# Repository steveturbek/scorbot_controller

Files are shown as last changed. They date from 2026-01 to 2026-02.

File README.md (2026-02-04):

# Scorbot Robot Controller

## Description

Arduino-based motor controller and software for rescued Scorbot ER III robot arm. MIT License.

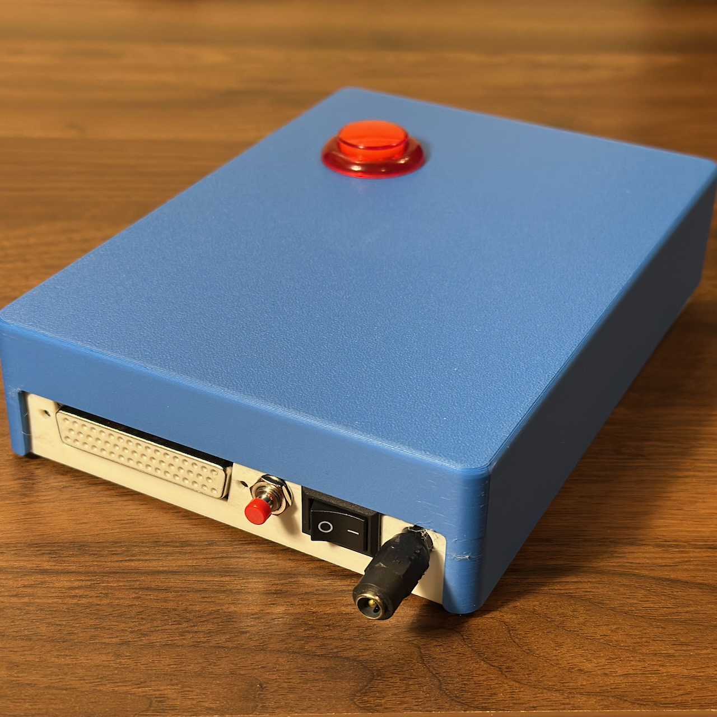
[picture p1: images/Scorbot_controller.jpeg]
Scorbot controller hardware

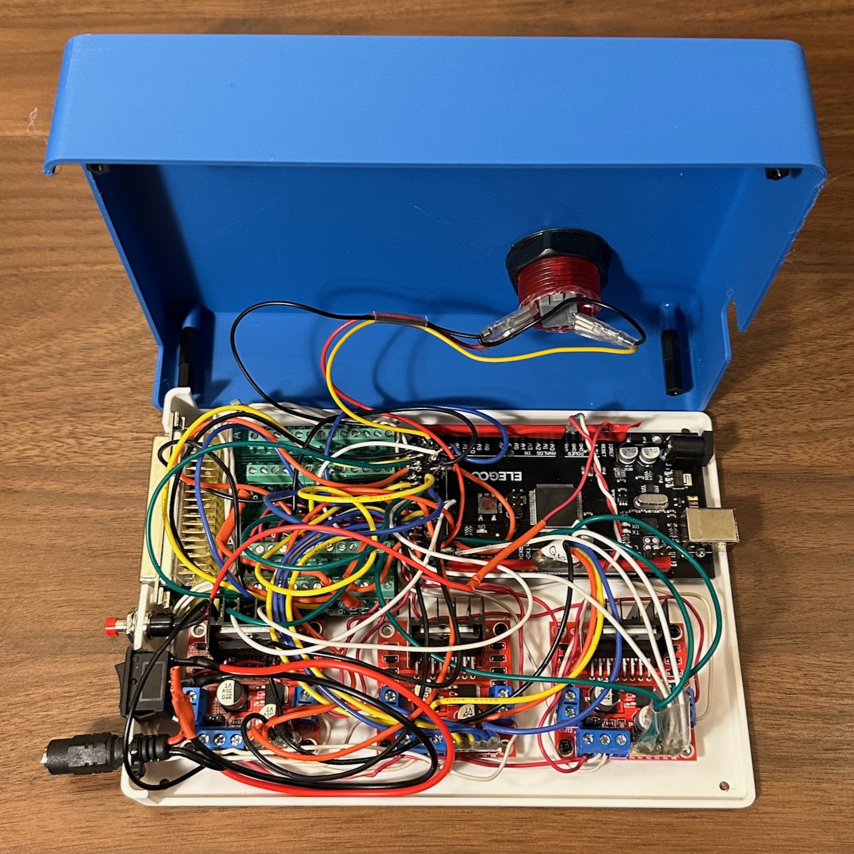
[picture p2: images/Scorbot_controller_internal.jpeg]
Scorbot controller hardware Internal


<video autoplay muted loop playsinline id="myVideo">
<source src="images/scorbot.mp4" type="video/mp4" />
</video>

[Video of Scorbot start up and simple motion demo](https://turbek.com/scorbot_controller/images/scorbot.mp4)

## Current Status

**Project Status: Complete (Hibernating)**

The controller is a demonstration of reviving a Scorbot ER III:

- All 6 axes move with PWM speed control
- All axes home correctly (gripper uses stall detection, others use microswitches)
- Position-based movement via encoder feedback
- Differential wrist control (pitch and roll motors work together)
- Goal-based queue system for sequencing movements
- Emergency stop functionality
- Demo sequence: homes all axes → picks up item → flips it → relocates

## Software Quick Start

1. **Upload firmware**: Load `scorbot_controller.ino` to Arduino Mega using Arduino IDE
2. **Connect Serial Monitor**: 115,200 baud to see debug output
3. **Power on**: Robot will home all axes sequentially, then run the demo sequence
4. **Modify behavior**: Edit the `setup()` function in `scorbot_controller.ino` to change the movement sequence

### Example: Adding a movement to the queue

```cpp
// Create a new goal group (movements in a group run in parallel)
queueCreateGoalGroup("move base and shoulder");
queueAddGoal(MOTOR_BASE, GOAL_MOVE_TO, 1050);      // Move base to position 1050
queueAddGoal(MOTOR_SHOULDER, GOAL_MOVE_TO, -500);  // Move shoulder to -500

// Wait 1 second before next group
queueCreateGoalGroupWait(1000);

// Gripper grab (move until stall detected)
queueCreateGoalGroup("grab item");
queueAddGoal(MOTOR_GRIPPER, GOAL_MOVE_TILL_STALL, 50);
```

## Key Code Entry Points

| File | Purpose |
| --- | --- |
| `scorbot_controller.ino` | Main firmware - modify `setup()` to change demo sequence |
| `scorbot.h` | Pin definitions, motor structs, speed thresholds |
| `helpers/pin_test/` | Diagnostic utility for verifying wiring |

### Key Functions

- `queueCreateGoalGroup(name)` - Start a new parallel movement group
- `queueAddGoal(motor, goalType, target)` - Add a motor goal to current group
- `queueCreateGoalGroupWait(ms)` - Add a pause between groups
- `queueAddGoalsFindHomeAll()` - Home all axes sequentially
- `queueStart()` - Begin executing the queue

### Goal Types

- `GOAL_FIND_HOME` - Search for home switch with edge detection
- `GOAL_MOVE_TO` - Move to encoder position
- `GOAL_MOVE_TILL_STALL` - Move until motor stalls (useful for gripper)

## Known Quirks & Lessons Learned

- **High PWM required**: Motors need high PWM values to overcome static friction. Elbow requires PWM 255; most others need 200+. See `motor_min_CW/CCW` in `scorbot.h`.
- **Stall detection timing**: Shoulder and Wrist Pitch are sensitive and need longer stall detection (400ms vs 100ms for others)
- **Gripper has no microswitch**: Uses stall detection when closed for homing
- **Differential wrist**: Wrist Pitch and Roll motors are mechanically coupled. Pure pitch = both same direction; pure roll = opposite directions. Handled automatically in firmware.
- **Home base last**: Base swings wildly during homing - the code homes it last for safety
- **Elbow issues**: Had mechanical problems during development; pin 27 connection was loose

## Potential Future Steps

The project is complete as a demostration of reviving the Scorbot, but future exploration could include:

- [] add direct joystick control
- [] add Microbit remote control for student project
- [] define and make a demo program, like moving a chess piece from one position to another
- [] define a way to write, store and load "programs" as external files
- [] measure end stops/stalls for each motor; update scorbot.h definitions
- [] Write "clean up" function to position motors near switches so the start up homing process goes faster
- [] add move to end/stall and stop function (good for picking up item with gripper)

## Project Log

- January 2026
  - Rough layout of parts on a board - the motors move!
  - modeled and printed controller case. Much easier thinking after just picking a layout. next time would just print base and areas under the ports.
  - Wired up mega, DB-50 connector and 3 L298N's. My soldering skills are very limited. I would use screw terminal shield for the Arduino Mega next time.
  - motors are working, basically. appear a bit slow, but power supply seems to be working. Desktop power supply reads roughly .5amps when motors are running.
  - the motors seems to need a high PWM value to move at all. I tested voltage across 12v power supply and PWM and appear in range.
  - `scorbot.h` is where I'm storing definitions and shared functions
  - `/helpers/` has working test files
  - `helpers/pin_test/pin_test.ino` was looking for shorts, etc in the arduino mega pins, due to my clumsy work. surprisingly I got it right on the first try
  - `helpers/motor_only_test/motor_only_test.ino` just moves the motors back and forth
  - `helpers/base_motor_test/base_motor_test.ino` is testing for homing and encoders for just the base motor
  - [Scorbot ER-4U](https://www.theoldrobots.com/book45/ER4u_User_Manual.pdf) seems to be essentially the same machine
  - note that Shoulder, Elbow, Wrist Pitch are built in such a way that wrist pitch remains consistent relative as shoulder and elbow move. Moving the shoulder does NOT simply swing the gripper tip relative to the shoulder. Moving the shoulder rotates the elbow to keep the wrist pitch steady. This is cool / confusing. probably needs kinematics
  - Arduino IDE is pretty slow. VS Code extension for arduino has been deprecated. PlatformIO looks too complicated for this project. Arduino Community Edition might work, but CLI, etc are too complicated at this point
  - installed CLANG to VSCode to get linting/formatting
  - MOTOR_ELBOW was a big pain, would not go CCW. turned out the CCW pin (arduinio pin 27) was loose
  - added Queue system to make sequence of actions

  - [x] add move to position
  - [x] add queue of goals, with parallel and sequential steps
  - [x] add all stop with interrupt
  - [x] make 'home' the CW clockwise side of the microswitch. there are ~200 encoder steps where the switch is depressed as the arm moves across the button.
  - [x] gripper home is stall when closed
  - [x] wrist pitch and roll movements depend on motors 4-5 working together differential drive
  - [x] shoulder find home
  - [x] write arduino code to get arm to move to home position
  - [x] make replacement microswitch cams
  - [x] 3D model top of case

- December 2025
  - modeled `scorbot joint cover with microswitch cam.stl`, printed and replaced cams. 1 original cam remains
  - ordered L298Ns, Arduino Mega, power supply

- August 2025
  - Got Scorbot ER III discarded by friends at NYC First. No controller or documentation
  - serial number 2090047 model "robot"
  - identified it as scorbot ER iii, found documentation and github projects.
  - Motors can be moved with basic 12v .5A power.
  - Gripper does not move, carefully opening it, seems like encoder case is bent, propellor hitting encoder and LEDs
  - Wrist roll microswitch is hanging off, which may be related.
  - I'm going to run motors on 12v power
  - all 5 microswitch work from switch leads and the pins
  - microswitch cam discs that trigger switches at home point are broken for shoulder, elbow, wrist. for shoulder, using broken pieces, looks like trigger radius is 30mm, clearance is 26-28mm. cup depth is 10mm, center hole dia is 6mm
  - Repaired the Gripper motor and the encoder, which was banged in. microswitch re-attached
  - gripper motor plate uses unusual 3.5mm hex for screws
  - using multimeter on Gripper and base, it seems motor encoders work!
  - Motors do NOT have auto stop switches at ends of rotation. assume they do it in software
  - cams are missing, but based on base, the 'home' position, where microswitch is, should be the center of movement.
  - confirmed Gripper encoder works, hand spinning disc. 47 ohm resistor works to LED. LED is infrared, not visible. photoresistor needs 10k pull up to 5v each to pin 0 and 1, where signal is read. (Arduino has this built in)
  - assuming other encoders work, proceeding with buying parts
  - arduino mega has 5v outputs
  - L298N H bridge enable pins can be PWM'd for speed control

### Project Goals

This is a messing around, learning project inspired by a free robot arm. The Scorbot ER III is a circa 1995 robot. So simple, maybe even I can work with it!

The goals of the project are to

1. Learn
1. Restore the basic functionality of movement and encoders
1. Design and build an arduino based controller that accepts a joystick-type controller and data input to operate.
1. Enable design students to design and build a microbit based joystick controller
1. Design and build a case

### When might I quit this project?

- If motors, or encoders stop working
- If costs go above $200
- If effort goes beyond a few weeks

## Project Parts List

- Scorbot ER iii robot arm, without controller or Teaching pendant (~$400-1000)
- [Arduino-type Mega board](https://a.co/d/h9p4QL3)
- [D-50 style connector board](https://a.co/d/717fIG9)
- [L298N dual h bridge motor controller](https://a.co/d/8DAa5Af)
- [12v 10 amp power supply](https://a.co/d/0ydMZDN)

## Scorbot Description

[Scorbot ER III Manual](/references/ER3-Manual.pdf)

### Summary

| Specification | Value |
| **Mechanical Structure** | Vertically articulated |
| **Axes** | 5 axes plus gripper |
| **Control** | 8 axes simultaneously |
| **Working Envelope** | |
| Axis 1: Base Rotation | 310° |
| Axis 2: Shoulder Rotation | +130° / –35° |
| Axis 3: Elbow Rotation | ±130° |
| Axis 4: Wrist Pitch | ±130° |
| Axis 5: Wrist Roll | Unlimited |
| **Maximum Working Radius** | 610 mm (24.4") |
| **Gripper Opening** | 75 mm (3") without rubber pads<br>65 mm (2.56") with rubber pads |
| **Maximum Work Load** | 1 kg (2.2 lb.) |
| **Transmission** | Gears, timing belts and lead screw |
| **Actuators** | 6 DC servo motors with closed-loop control |
| **Feedback** | Optical encoders on all axes |
| **Hard Home** | Fixed reference position on all axes |
| **Repeatability** | ±0.5 mm (±0.02") |
| **Maximum Speed** | 330 mm/sec. (13"/sec.) |
| **Weight** | |
| Robot Arm | 11 kg (24 lb.) |
| Controller | 5 kg (11 lb.) |

### Original power supply

- - 15V, 4A, unregulated, supplies power to the robot motors.
- –15V, 4A, unregulated, supplies power to the robot motors.
- - 5V, 1.5A, regulated, supplies power to the microprocessor, the memory and the logic in the control circuit.
- - 12V, 0.4A, regulated, supplies power to the I/O circuitry outputs, and to the RS232 communications.
- –12V, 0.4A, regulated, supplies power to the RS232 communications.

### Motors

- Motors 1,2,3 Pittman GM9413G608 127.7:1 ratio
- Motors 4,5 Pittman GM9413F759 65.5:1 ratio
- Motor 6 Gripper Pittman GM8712F297 19.5:1 ratio

### Scorbot Cable connector

The Scorbot cable connector is an [DB 50](https://en.wikipedia.org/wiki/D-subminiature) cable. Connectors and breakout boards that fit are available at Amazon or Ali Express. [DB 50 connector Specification](https://www.farnell.com/datasheets/1656989.pdf) [DB50 diagram](https://upload.wikimedia.org/wikipedia/commons/a/af/DD50_Diagram.svg)

Here is the pin numbers (looking at the male scorbot cable connector pins)

<pre>
────────────────────────────────────────────────────────────────────────────────────────────
╲   (1)  (2)  (3)  (4)  (5)  (6)  (7)  (8)  (9)  (10) (11) (12) (13) (14) (15) (16) (17)   ╱
 ╲    (18) (19) (20) (21) (22) (23) (24) (25) (26) (27) (28) (29) (30) (31) (32) (33)     ╱
  ╲ (34) (35) (36) (37) (38) (39) (40) (41) (42) (43) (44) (45) (46) (47) (48) (49) (50) ╱
    ─────────────────────────────────────────────────────────────────────────────────────
</pre>

## SCORBOT ER III WIRING GUIDE

### TABLE 1: DB-50 CONNECTOR TO ARDUINO MEGA

| DB-50 Pin | Motor | Joint | Signal | Arduino Pin | L298N Board | L298N Input | L298N Output | Notes |
| --- | ----- | --- | --- | --- | --- | --- | --- | --- |
| 1 | 2 | Shoulder | Encoder P0 | 36 | | | | |
| 2 | 1 | Base | Encoder P0 | 34 | | | | |
| 3 | 5 | Wrist Roll  | Encoder P1 | 43 | | | | |
| 4 | 3 | Elbow | Encoder P1 | 39 | | | | |
| 5 | 1 | Base | Encoder P1 | 35 | | | | |
| 6 | 5 | Wrist Roll  | Microswitch | 50 | | | | |
| 7 | 2 | Shoulder | Microswitch | 47 | | | | |
| 8 | 4 | Wrist Pitch | Microswitch | 49 | | | | |
| 9 | 5 | Wrist Roll  | Encoder LED | 5V via 47Ω  | | | | |
| 10 | 3 | Elbow | Encoder LED | 5V via 47Ω  | | | | |
| 11 | 1 | Base | Encoder LED | 5V via 47Ω  | | | | |
| 12 | 6 | Gripper | Motor + | 32 | 3 | 3 | 3 | |
| 13 | 5 | Wrist Roll  | Motor + | 30 | 3 | 1 | 1 | |
| 14 | 4 | Wrist Pitch | Motor + | 28 | 2 | 3 | 3 | |
| 15 | 3 | Elbow | Motor + | 26 | 2 | 1 | 1 | |
| 16 | 2 | Shoulder | Motor + | 24 | 1 | 3 | 3 | |
| 17 | 1 | Base | Motor + | 22 | 1 | 1 | 1 | |
| 18 | 5 | Wrist Roll  | Encoder P0 | 42 | | | | |
| 19 | 6 | Gripper | Encoder P1 | 44 | | | | |
| 20 | 4 | Wrist Pitch | Encoder P1 | 41 | | | | |
| 21 | 2 | Shoulder | Encoder P1 | 37 | | | | |
| 22 | 6 | Gripper | Microswitch | - | | | | manual says not connected |
| 23 | 1 | Base | Microswitch | 46 | | | | |
| 24 | 3 | Elbow | Microswitch | 48 | | | | |
| 25 | 6 | Gripper | Encoder LED | 5V via 47Ω  | | | | |
| 26 | 4 | Wrist Pitch | Encoder LED | 5V via 47Ω  | | | | |
| 27 | 2 | Shoulder | Encoder LED | 5V via 47Ω  | | | | |
| 28 | 6 | Gripper | Encoder GND | GND | | | | |
| 29 | 5 | Wrist Roll  | Switch & Encoder GND | GND | | | | |
| 30 | 4 | Wrist Pitch | Switch & Encoder GND | GND | | | | |
| 31 | 3 | Elbow | Switch & Encoder GND | GND | | | | |
| 32 | 2 | Shoulder | Switch & Encoder GND | GND | | | | |
| 33 | 1 | Base | Switch & Encoder GND | GND | | | | |
| 34 | 6 | Gripper | Encoder P0 | 45 | | | | |
| 35 | 4 | Wrist Pitch | Encoder P0 | 40 | | | | |
| 36 | 3 | Elbow | Encoder P0 | 38 | | | | |
| 37 | - | - | - | - | | | | |
| 38 | - | - | - | - | | | | |
| 39 | - | - | - | - | | | | |
| 40 | - | - | - | - | | | | |
| 41 | - | - | - | - | | | | |
| 42 | - | - | - | - | | | | |
| 43 | - | - | - | - | | | | |
| 44 | - | - | - | - | | | | |
| 45 | 6 | Gripper | Motor - | 33 | 3 | 4 | 4 | |
| 46 | 5 | Wrist Roll  | Motor - | 31 | 3 | 2 | 2 | |
| 47 | 4 | Wrist Pitch | Motor - | 29 | 2 | 4 | 4 | |
| 48 | 3 | Elbow | Motor - | 27 | 2 | 2 | 2 | |
| 49 | 2 | Shoulder | Motor - | 25 | 1 | 4 | 4 | |
| 50 | 1 | Base | Motor - | 23 | 1 | 2 | 2 | |
| - | 1 | Base | PWM (motor speed) | 7 | 1 | | ENA | |
| - | 2 | Shoulder | PWM (motor speed) | 6 | 1 | | ENB | |
| - | 3 | Elbow | PWM (motor speed) | 5 | 2 | | ENA | |
| - | 4 | Wrist Pitch | PWM (motor speed) | 4 | 2 | | ENB | |
| - | 5 | Wrist Roll  | PWM (motor speed) | 3 | 3 | | ENA | |
| - | 6 | Gripper | PWM (motor speed) | 2 | 3 | | ENB | |
| - | - | - | - | 52 | | | | Emergency Stop Button |

### TABLE 2: POWER CONNECTIONS

| Component | Connection | Source | Notes |
| --- | --- | --- | --- |
| Arduino Mega | 12V Vin | Common 12v plug or Barrel Jack | Powers logic |
| Arduino Mega | GND | Common Ground | Shared with all components |
| L298N Board 1-3 | 12V | 12V 10A Power Supply | Motor power |
| L298N Board 1-3 | GND | Common Ground | Shared ground |
| Encoder LEDs (6x) | 5V | Arduino 5V via 47Ω resistor | One resistor per encoder |
| Encoder LEDs GND  | GND | DB-50 pins 28-33 | Common ground |

### SERIAL COMMUNICATION

| Function | Arduino Pin | Purpose |
| --- | --- | --- |
| TX | 18 | Serial1 - transmit to joystick controller  |
| RX | 19 | Serial1 - receive from joystick controller |

### WIRING TIPS

1. **Label everything** - use labels/tape on wires at both ends
2. **Color coding:**
   - Red: 12V power
   - Black: GND
   - Yellow/Green: encoders
   - Blue: microswitches
   - Other colors: motor control signals
3. **Use a breakout board** for the DB-50 connector
4. **Bundle by function** - keep motor, encoder, and switch wires separated
5. **Consider a prototype shield** or custom PCB for clean organization

## Spec sheets and Manuals

- [Scorbot ER III Manual](https://www.theoldrobots.com/book45/ER3-Manual.pdf)
- [Arduino Mega sheet](https://content.arduino.cc/assets/Pinout-Mega2560rev3_latest.pdf)
- [Arduino Mega details](https://docs.arduino.cc/hardware/mega-2560/)
- [L298N dual H bridge motor controller](https://www.handsontec.com/dataspecs/L298N%20Motor%20Driver.pdf)

## CAD

- [SCORBOT ER4u Robotic Arm](https://grabcad.com/library/scorbot-er4u-robotic-arm-1)
- [L298N dual H bridge motor controller](https://grabcad.com/library/motor-driver-l298n-2)
- [DB50 Connector](https://grabcad.com/library/panel-connector)
- [DB50 dimensions](https://my.misumi-ec.com/linked/item/10500001630/img/SEA_oth_04large.gif)
- [Arduino Mega](https://grabcad.com/library/arduino-mega-17)

## Diagrams

Arduino Mega

DB50 Breakout board

DC motor

L298N motor controller

## Scorbot GitHub Projects

| Project Name | Associated Web Pages | Brief Description |
| --- | --- | --- |
| [**Scorbot**](https://github.com/amiravni/Scorbot) | • [GitHub](https://github.com/amiravni/Scorbot/blob/master/scorbotOldTestCode/ScorbotCmd/ScorbotCmd.ino) <br>[My Name is Scorbot](http://www.whatimade.today/my-name-is-scorbot/)<br> [Scorbot learns to draw"](http://whatimade.today/geekcon-xii-scorbot-learns-to-draw/) | Arduino MEGA-based controller for Scorbot ER-V with 6-encoder system, custom PCB shield, and Python drawing capabilities. Complete reverse engineering from junkyard condition. |
| [**robotic-arm**](https://github.com/ethanleep/robotic-arm) | • [Scorbot ER-III Manual](https://usermanual.wiki/Document/Scorbot20ERIII20manual.259237025/help) | Custom controller replacement for Scorbot-ER III with serial and hard-coded control modes. Arduino-based system with comprehensive reference documentation. |
| [**Scorbot**](https://github.com/luisp23/Scorbot) | • [Author's Portfolio](https://www.luispimen.com/)<br>• [CS 287: Advanced Robotics Course](https://people.eecs.berkeley.edu/~pabbeel/cs287-fa19/) | Arduino-based joystick controller for Scorbot robotic arm as cost-effective alternative to expensive original controller. Georgia Tech ECE project. |
| [**Scorbot-ER-V-Simulator-Controller**](https://github.com/aamitn/Scorbot-ER-V-Simulator-Controller) | • [Hackster.io Project](https://www.hackster.io/amitnandileo/scorbot-er-v-controller-simulator-design-1a2d6f)<br>• [Arduino Project Hub](https://create.arduino.cc/projecthub/amitnandileo/scorbot-er-v-controller-simulator-design-1a2d6f)<br>• [Author's Website](https://aamitn.github.io/)<br>• [ResearchGate Profile](https://www.researchgate.net/profile/Amit-Nandi) | Professional-grade MATLAB simulation software and hardware controller for Scorbot ER-V+ with PID control, ROS integration, and industrial safety features. |
| [**OpenScorbot**](https://github.com/jamofer/OpenScorbot) | • Author: Software Engineer at Casa-Systems | Complete open-source hardware/software controller replacement for SCORBOT ER-IX. |
| [**ScorBotToolbox**](https://github.com/kutzer/ScorBotToolbox) | • [USNA Documentation](https://www.usna.edu/Users/weapron/kutzer/_Code-Development/ScorBot_Toolbox.php)<br>• [MATLAB File Exchange](https://www.mathworks.com/matlabcentral/fileexchange/52830-kutzer-scorbottoolbox)<br>• [Legacy MTIS Toolbox](https://www.usna.edu/Users/weapsys/esposito/scorbot.matlab.php) | MATLAB toolbox for interfacing and simulating Intelitek ScorBot-ER 4U educational robot with comprehensive control and visualization capabilities. |
| [**ED-Scorbot**](https://github.com/RTC-research-group/ED-Scorbot) | • [University Research Page](http://www.rtc.us.es/ed-scorbot)<br>• [ROS Simulation](http://www.rosject.io/l/11c04055/) | Event-based Scorbot ER-VII platform for neuromorphic research with spike-based controllers, FPGA integration, and spiking neural networks. |
| [**scorbot**](https://github.com/rorromr/scorbot) | • Limited documentation available | Scorbot ER-VII implementation with basic functionality. |
| [**SCORBOT-ER-VII**](https://github.com/JHONAURBANOD/SCORBOT-ER-VII) | • Gazebo simulation files included | Contains simulation files for Scorbot ER-VII in Gazebo robotics simulator environment. |
| [**scorbot-simulator**](https://github.com/oscarjcg/scorbot-simulator) | • [YouTube Demo](https://www.youtube.com/watch?v=9E7pBUh7wQg)<br>• [Documentation](https://alu0100825893.github.io/ScorbotSimulator/Docs/html/annotated.html) | Unity-based Scorbot simulator with graphic interface, includes video demonstrations and comprehensive Doxygen documentation. Built with Unity 2017.4.1f1. |
| [**openScorbot**](https://github.com/tidus747/openScorbot) | • Spanish documentation included | Free controller for Scorbot ER-4U with Python 3.6.9 and Qt 5 Designer GUI. |
| [**scorbot**](https://github.com/PlanBCode/scorbot) | • Processing-based interface documentation | Processing code for mouse-controlled Scorbot-ER V Plus with coordinate mapping system. Future goal: Game of Life with marbles. |
| [**scorbot_config**](https://github.com/greenpro/scorbot_config) | • [CraigCode1010.com](http://craigcode1010.com/)<br>• Complete SAC project documentation | Configuration files for Scorbot integration with MoveIt motion planning framework. Part of SAC (Scorbot Arm Control) project. |
| [**sac_description**](https://github.com/greenpro/sac_description) | • [Project Documentation](http://craigcode1010.com/)<br>• ROS system topology details | ROS package with URDF descriptions for Southern Adventist University robotic arm simulation, includes Scorbot modeling for Gazebo. |
| [**r2d3**](https://github.com/ajnsit/r2d3) | • Cross-platform simulator documentation | Free robotic manipulator simulator using Blender and Python, specifically designed for Scorbot ER-V with forward/inverse kinematics and ACL programming support. |
| [**sboter4u**](https://github.com/baijuch/sboter4u/tree/master) | • Scorbot ER4U robot configuration using Moveit | |

### Other Robot Arm Projects

- [PAROL6](https://github.com/PCrnjak/PAROL6-Desktop-robot-arm)
- [BCN3D Moveo](https://github.com/BCN3D/BCN3D-Moveo)
- [LeRobot](https://github.com/huggingface/lerobot)
- [Faze4-Robotic-arm](https://github.com/PCrnjak/Faze4-Robotic-arm)

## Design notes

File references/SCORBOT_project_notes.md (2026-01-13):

# SCORBOT Controller Projects by other people Notes

## Analysis of GitHub Projects for Arduino Mega Implementation

## **Date:** January 2026

## Executive Summary

### Gripper Home Switch Answer

**The ER-III gripper does NOT have a home switch.**

From manual (Table D-1, pin 22): "Gripper Microswitch - manual says not connected"

From amiravni's blog: "Six more pins are connected to the microswitches but in fact there are only 5, the gripper does not have a microswitch but there's a pin kept for that option."

### Gripper Calibration Strategies Found:

1. **Current sensing method** - Close until motor stalls (controlled current limit)
2. **Encoder-based soft limits** - Store min/max values after manual calibration
3. **Zero at fully closed** - Set position to 0 when fully closed, track from there
4. **Use encoder counts** - Track relative position from known state

---

## Project Analysis

### 1. **amiravni/Scorbot** MOST RELEVANT

**Platform:** Arduino MEGA + L293D drivers  
**Scorbot Model:** ER-V (very similar to ER-III)  
**Status:** Working, used for drawing

#### Key Technical Decisions:

- **Encoder reading:** Timer-based interrupt polling (~300ns per check)
- **Motor control:** Simple PWM through L293D (no PID initially)
- **Homing:** Microswitch interrupts zero encoder counters
- **Gripper:** No home switch, encoder-based positioning
- **Communication:** Serial commands from Python
- **Custom PCB shield:** Created for clean wiring

#### Code Architecture:

```
ScorbotCOMcontrol/ - Main controller (serial commands)
Encoder_Scorbot/   - Modified encoder library
python/            - Drawing control software
```

#### Critical Insights:

- "For each encoder we define a counter, and when the interrupt is activate (occurs about every ~300ns) it executes a function which checks the 6 encoders P0 and P1 pins"
- Encoder library: Polls all 6 encoders in single fast interrupt
- Microswitches trigger interrupts to zero position
- Successfully controlled 6 motors + drew complex images

#### Limitations Noted:

- No PID control initially (later versions may have added)
- Simple open-loop position control
- No trajectory planning

---

### 2. **ethanleep/robotic-arm (via usermanual.wiki)**

**Platform:** Arduino MEGA + STM32 "Blue Pill" + L239D drivers  
**Scorbot Model:** ER-III  
**Status:** Working controller with joystick interface

#### Key Technical Decisions:

- **Architecture:** Distributed - STM32 for each motor pair
- **Communication:** I2C between main controller and motor boards
- **Motor control:** L239D H-bridges
- **Encoders:** Filter circuitry added to clean signals
- **Joystick control:** Limit switch-based joysticks (5V when active)

#### Code Architecture:

- Main controller: USB communication + I2C coordinator
- Motor boards: Independent encoder reading + motor control
- Breakout board: Custom PCB for DB-50 connector

#### Critical Insights:

- Motor current: ~400mA normal operation at 12V
- Encoder LEDs: 2.3V requirement
- Only axes 0 and 2 used limit switches (partial homing)
- Power supply: 14V DC main, 2.4V for LEDs, 5V for logic

#### Advantages:

- Distributed processing reduces Arduino load
- Filter circuitry improves encoder reliability
- Joystick interface for manual control

---

### 3. **luisp23/Scorbot**

**Platform:** Arduino-based joystick controller  
**Scorbot Model:** ER-III or similar  
**Status:** Alternative to expensive controller

#### Key Insights:

- Focused on joystick control as primary interface
- Cost-effective replacement strategy
- ECE project from Georgia Tech
- Minimal documentation but working prototype

---

### 4. **aamitn/Scorbot-ER-V-Simulator-Controller** PROFESSIONAL GRADE

**Platform:** Arduino + MATLAB + ROS  
**Scorbot Model:** ER-V+  
**Status:** Complete system with simulation

#### Key Technical Decisions:

- **Motor control:** PID position control
- **Kinematics:** Full forward/inverse kinematics in MATLAB
- **Safety:** Industrial-grade emergency stop system
- **Interface:** Teach pendant + computer control
- **Simulation:** Complete MATLAB simulator before hardware

#### Code Architecture (MATLAB):

```matlab
@scorbot/Scorbot.m - Main class
SSCdirectModel()   - Forward kinematics
SSCmotorsToThetas() - Motor to joint conversion
SSCthetasToMotors() - Joint to motor conversion
```

#### Critical Insights:

- PID control essential for accuracy
- Separate motor/joint coordinate systems
- Gripper sensor support for force control
- Display system for real-time feedback
- Uses ROS for advanced control

#### Professional Features:

- Error handling with diagnostic LEDs
- Integrated display showing status
- Serial interface for programming
- Safety interlocks throughout

---

### 5. **jamofer/OpenScorbot**

**Platform:** BeagleBone (HRobot) + LPC1768 (LRobot)  
**Scorbot Model:** ER-IX  
**Status:** Complete hardware/software replacement

#### Key Insights:

- Two-tier architecture: High-level + Low-level
- LPC1768 for real-time motor control
- BeagleBone for kinematics/planning
- Noted as "poor code quality" by author (learning project)

---

### 6. **kutzer/ScorBotToolbox** BEST DOCUMENTATION

**Platform:** MATLAB toolbox  
**Scorbot Model:** ER-4U  
**Status:** Production-ready, USNA educational use

#### Key Insights:

- Comprehensive visualization tools
- Extensive error checking
- Well-documented API
- Requires original Intelitek controller
- Excellent reference for kinematics equations

---

### 7. **tidus747/openScorbot**

**Platform:** Python 3.6.9 + Qt 5 GUI  
**Scorbot Model:** ER-4U  
**Status:** Free controller with GUI

#### Key Insights:

- High-level language (Python) for control
- GUI-based interface
- Focuses on user-level control
- No low-level kinematics

---

### 8. **Hackaday.io ROBOT ARM project**

**Platform:** Arduino MEGA + Raspberry Pi + LM298 drivers  
**Scorbot Model:** ER-V  
**Status:** Shelved but functional

#### Key Technical Decisions:

- **Motor control:** "Terribly-tuned PID loops"
- **Kinematics:** Full forward/inverse kinematics
- **Interface:** G-code-like text commands
- **Architecture:** Arduino for motor control, Pi for planning

#### Critical Quote:

- "an underpowered microcontroller to run the kinematics"
- Used Arduino PID library (modified)
- Linear interpolation for smooth paths
- Linear speed control

#### Lessons Learned:

- Arduino MEGA struggles with kinematics calculations
- PID tuning is difficult and critical
- Separate planning/execution is beneficial

---

## Motor Control Strategies Summary

### Simple PWM (No PID)

**Used by:** amiravni initial version  
**Pros:** Simple, fast response  
**Cons:** No accuracy, overshoot, oscillation  
**Best for:** Initial testing, manual control

### Position PID Control

**Used by:** aamitn, Hackaday project  
**Pros:** Accurate positioning, smooth motion  
**Cons:** Requires tuning, computational overhead  
**Best for:** Autonomous operation, precision tasks

### Distributed Control

**Used by:** ethanleep  
**Pros:** Offloads processing, modular  
**Cons:** Complex wiring, multiple boards  
**Best for:** Professional builds

---

## Encoder Reading Strategies

### 1. **Fast Timer Interrupt (amiravni)**

```cpp
// Poll all encoders in single interrupt ~300ns
ISR(TIMER_OVF) {
    for each encoder:
        check P0, P1 pins
        update counter (+1, -1, or 0)
}
```

**Pros:** Single interrupt, efficient  
**Cons:** Might miss fast pulses

### 2. **Pin Change Interrupts (Standard Arduino)**

```cpp
// Separate interrupt per encoder channel
attachInterrupt(P0_pin, encoder_ISR, CHANGE);
```

**Pros:** Never misses pulses  
**Cons:** Many interrupts, overhead

### 3. **Polling in Main Loop**

**Pros:** Simple, no interrupts  
**Cons:** Slow, unreliable, NOT RECOMMENDED

### Recommendation:

Use Arduino Encoder library with hardware interrupts for critical axes (base, shoulder), timer interrupts for others.

---

## Homing Strategies

### Full Home Search (5 axes)

```
1. Move each axis slowly until microswitch triggers
2. Back off slightly
3. Approach slowly again for accuracy
4. Set encoder position to 0
5. Move to defined home position
```

### Partial Home (ethanleep approach)

- Only home base (axis 1) and shoulder (axis 2)
- Other axes use relative positioning
- **Risk:** Cumulative error over time

### No Home Option

- Start from arbitrary position
- Store position to EEPROM on shutdown
- Restore on startup
- **Risk:** Lost if power fails during operation

### Recommendation:

Full home search on startup. All 5 axes have working microswitches in your robot.

---

## Gripper Calibration (No Home Switch)

### Method 1: Current Sensing

```cpp
void calibrateGripper() {
    closeGripperUntilStall();  // Monitor current
    encoderCount_gripper = 0;   // This is fully closed
    openGripper(MAX_OPEN);      // Known max opening
    // Now have calibrated range
}
```

### Method 2: Manual Calibration

```cpp
// User manually positions gripper
// Store encoder values
int gripperMinPosition = 0;      // Fully closed
int gripperMaxPosition = 2500;   // Fully open (measured)
```

### Method 3: Soft Limits from Encoder

```cpp
// First run: discover limits
while (movingGripper) {
    if (encoderNotChanging && motorActive) {
        // Hit limit, record position
    }
}
```

### Recommendation:

Use Method 1 (current sensing) with low current limit for safety.

---

## Communication Protocols

### Serial Commands (Most Common)

```
Format: "M<axis><direction><steps>\n"
Example: "M1+500\n"  // Move axis 1 forward 500 steps
```

### G-code Style (Hackaday project)

```
Format: "X<x> Y<y> Z<z> A<angle>\n"
Example: "X100 Y50 Z200 A45\n"
```

### Binary Protocol (Professional)

- Fixed-size packets
- Checksums for reliability
- Higher throughput

### Recommendation:

Start with simple ASCII serial, upgrade to binary if needed.

---

## Power Supply Considerations

### From Projects:

- **amiravni:** 12V for motors via L293D
- **ethanleep:** 14V DC main supply
- **aamitn:** PID control with 12V nominal
- **Manual specs:** Motors rated 12V, 400mA typical

### Voltage Options:

1. **12V regulated:** Safest, matches motor rating
2. **14V-15V unregulated:** More torque, original spec
3. **Variable (PWM):** Best control, requires good drivers

### Your L298N Boards:

- Rated up to 46V input
- 2A per channel
- Built-in 5V regulator
- **Recommendation:** Use 12V supply, PWM for speed control

---

## Arduino Mega Capabilities

### Confirmed Working Projects:

- amiravni: Full 6-axis control + drawing
- ethanleep: Full control with distributed architecture
- Hackaday: "underpowered" for kinematics but worked

### Pin Availability Check:

- **PWM outputs needed:** 6 (ENA/ENB for 3x L298N) ✓ Have 15 PWM pins
- **Direction outputs:** 12 (IN1-4 for 3x L298N) ✓ Plenty of digital pins
- **Encoder inputs:** 12 (P0/P1 for 6 motors) ✓ Have 6 hardware interrupts + many digital
- **Microswitch inputs:** 5 ✓
- **Serial comm:** 1 (plus 3 additional Serial ports) ✓

### Conclusion:

Arduino Mega is MORE than capable. Timer interrupts + hardware interrupts sufficient.

---

## Architecture Recommendations

### Phase 1: Basic Motor Control

```
Arduino Mega → L298N boards → Motors
         ↓
    Read encoders (interrupts)
    Read microswitches
    Serial control from PC
```

### Phase 2: Add Positioning

```
+ Implement home search
+ Position tracking with encoders
+ Go-to-position commands
+ Soft limits for safety
```

### Phase 3: Add Intelligence

```
+ PID control loops
+ Speed ramping (acceleration/deceleration)
+ Coordinated multi-axis moves
+ Trajectory planning (if needed)
```

### Phase 4: Advanced (Optional)

```
+ Kinematics (forward/inverse)
+ Path planning
+ Vision integration
+ ROS interface
```

---

## Critical Code Patterns

### Encoder Reading (from amiravni pattern):

```cpp
volatile long encoderCount[6] = {0};

void setupEncoders() {
    // Set up timer for fast polling
    TCCR1B = 0;  // Stop timer
    TCNT1  = 0;  // Reset counter
    TCCR1B |= (1 << CS10); // No prescaling = ~16MHz
    TIMSK1 |= (1 << TOIE1); // Enable overflow interrupt
}

ISR(TIMER1_OVF_vect) {
    for(int i=0; i<6; i++) {
        byte p0 = digitalRead(encoder_P0[i]);
        byte p1 = digitalRead(encoder_P1[i]);

        if(p0 != lastP0[i]) {
            if(p0 == p1) encoderCount[i]++;
            else encoderCount[i]--;
            lastP0[i] = p0;
        }
    }
}
```

### Homing Routine Pattern:

```cpp
void homeAxis(int axis) {
    // Move backward slowly
    setMotorSpeed(axis, -HOMING_SPEED);

    // Wait for microswitch
    while(!digitalRead(limitSwitch[axis])) {
        delay(10);
    }

    // Stop motor
    setMotorSpeed(axis, 0);

    // Zero encoder
    encoderCount[axis] = 0;

    // Back off switch
    moveToPosition(axis, BACKOFF_DISTANCE);
}
```

### Position Control Pattern:

```cpp
void moveToPosition(int axis, long targetPos) {
    long error = targetPos - encoderCount[axis];

    while(abs(error) > POSITION_TOLERANCE) {
        error = targetPos - encoderCount[axis];

        // Simple proportional control
        int speed = constrain(error * Kp, -MAX_SPEED, MAX_SPEED);
        setMotorSpeed(axis, speed);

        delay(10);
    }

    setMotorSpeed(axis, 0);
}
```

---

## Lessons from Failed Approaches

### Don't Do:

1. **Skip encoder filtering** - Noise causes position drift
2. **No home routine** - Impossible to recover from errors
3. **Ignore motor stall detection** - Can damage mechanics
4. **Run motors continuously at full voltage** - Overheating
5. **No emergency stop** - Safety critical
6. **Complex kinematics on Mega** - Slow, use PC instead

### Do:

1. **Test motors individually first**
2. **Test encoders separately**
3. **Add serial debug output**
4. **Implement soft limits**
5. **Start without PID, add later**
6. **Keep kinematics on PC/Python**

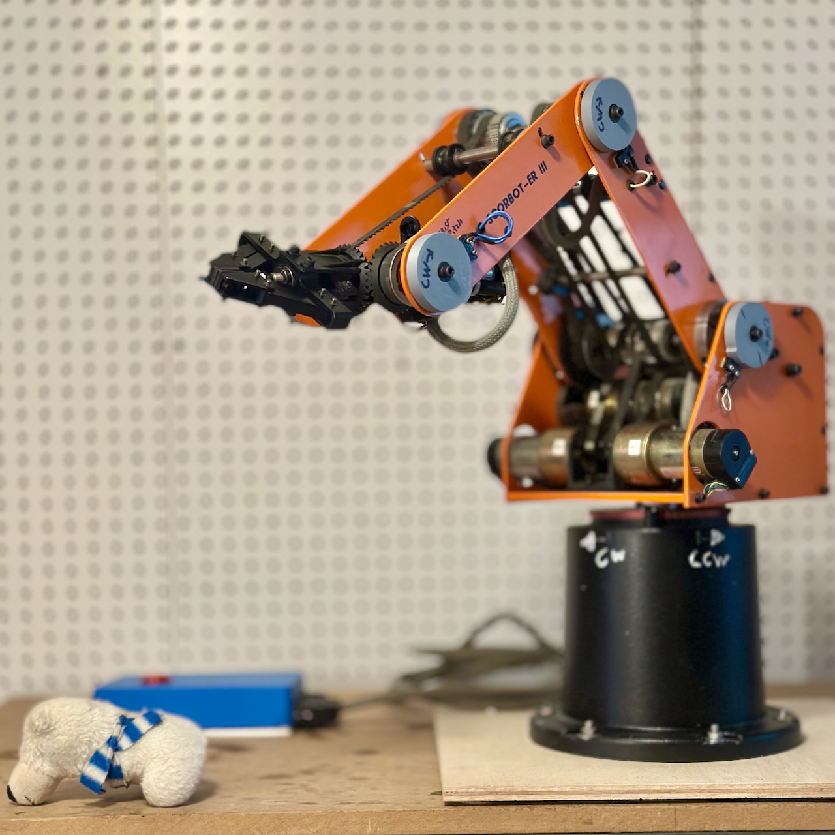
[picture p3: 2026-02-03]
images/scorbot.jpeg

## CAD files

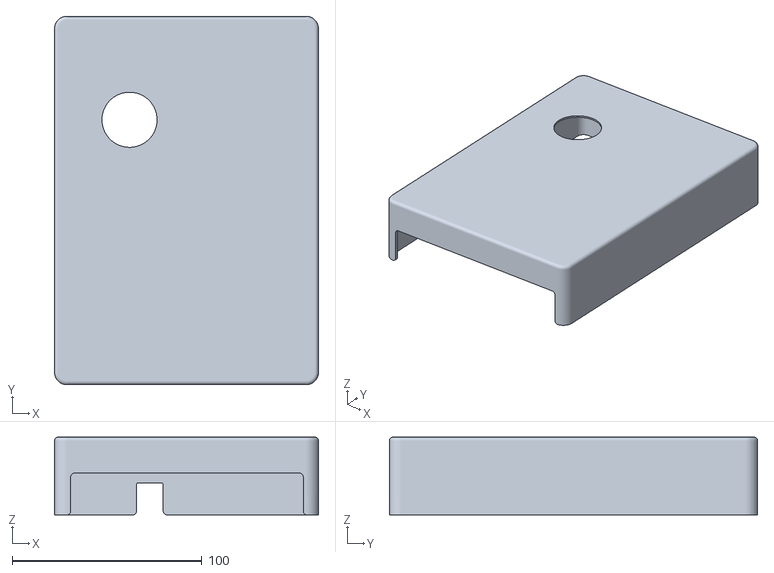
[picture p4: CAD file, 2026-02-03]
3Dfiles/scorbotIIIER-controller-top.stl
139.0 x 194.0 x 41.0

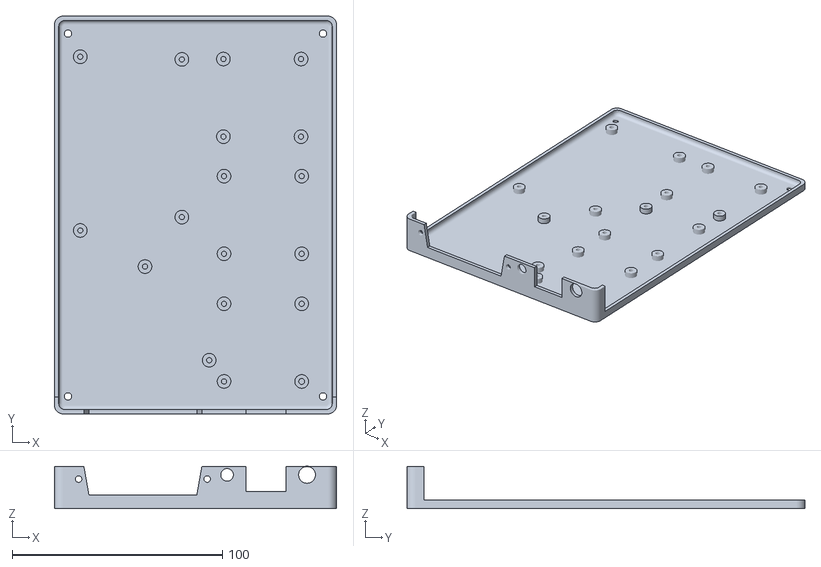
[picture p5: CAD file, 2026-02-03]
3Dfiles/scorbotIIIER-controller-base.stl
134.0 x 189.0 x 20.0

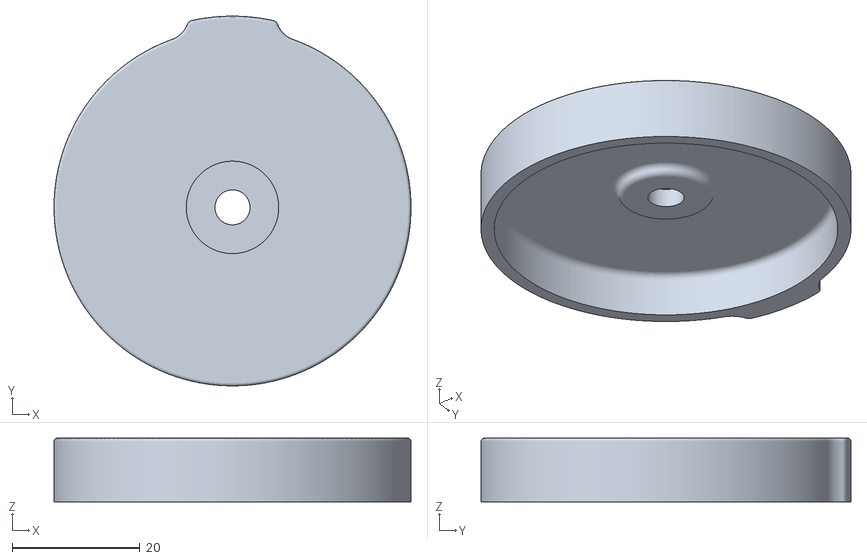
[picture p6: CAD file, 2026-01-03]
3Dfiles/scorbot joint cover with microswitch cam.stl
56.0 x 58.0 x 10.0

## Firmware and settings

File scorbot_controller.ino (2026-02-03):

/*
SCORBOT ER III controller program

Controls a 6-axis SCORBOT robot arm via DC motors with quadrature encoders.
Provides goal-based joint control (homing, move-to-position) with stall detection,
differential wrist drive, and a queue system for sequencing multi-joint movements.

setup() initializes hardware, then builds and starts a goal queue defining the motion sequence.
loop() polls encoders, checks stalls and home switches, executes goals, and advances the queue.
Edit the queueAddGoal() calls in setup() to change the robot's movement sequence.

This is a not a complete control system, but is a robust start for expanding to more complex projects.

See Readme for next steps in project.

*/

#include <Arduino.h>

// this is the definitions of pins and hardware
#include "scorbot.h"

// Goal-based states
enum JointGoal {
  GOAL_IDLE,                 // No active goal, motor at rest
  GOAL_FIND_HOME,            // Find home switch and set position to 0
  GOAL_RETURN_HOME,          // Fast travel toward home, then edge detection (use after initial homing)
  GOAL_CALIBRATE_RANGE_CW,   // Find CW limits from home
  GOAL_CALIBRATE_RANGE_CCW,  // Find CCW limits from home
  GOAL_MOVE_TO,              // Move to target encoder position
  GOAL_WAIT,                 // Wait for specified duration (no motor movement)
  GOAL_MOVE_TILL_STALL,      // Move until stall detected (for gripper grab, etc.)
  GOAL_FAULT                 // Error condition, requires reset
};

// Goal names for debugging
const char* MOTOR_GOAL_NAMES[] = {"IDLE",    "FIND_HOME", "RETURN_HOME",     "CALIBRATE_RANGE",
                                  "MOVE_TO", "WAIT",      "MOVE_TILL_STALL", "FAULT"};

struct ScorbotJointState {
  bool hasFoundHome;  // Whether home switch has been located

  // Motor control
  int motorSpeed;  // value (-99 for CCW speed, 0 for stop and 99 for CW)
  // will be interpreted using the min numbers for the individual motor

  JointGoal currentGoal;        // Current goal being pursued
  unsigned long goalStartTime;  // When current goal started

  long targetEncoderCountToMoveTo;           // Target encoder count (for GOAL_MOVE_TO)
  long maxEncoderStepsFromHomeCW;            // CW limit from home.   (0 = uncalibrated)
  long maxEncoderStepsFromHomeCCW;           // CCW limit from home (0 = uncalibrated)
  unsigned long lastHomeSwitchDebounceTime;  // For home switch debouncing
  bool lastHomeSwitchPressed;                // Previous switch state for edge detection

  // Encoder tracking
  long encoderCount;      // Current encoder position
  long lastEncoderCount;  // Previous count for stall detection
  int lastEncoded;        // Last 2-bit encoder state (for quadrature)

  // Timing and stall detection
  unsigned long lastEncoderCheckTime;  // For stall detection interval
  int stallCounter;                    // Consecutive stall checks
  int totalStallsThisGoal;             // Total stalls since goal started (for fault detection)
};

// Array of states, one per motor (initialize with zeros)
ScorbotJointState jointState[ScorbotJointIndex_COUNT];

// ============================================================================
// GOAL QUEUE SYSTEM
// ============================================================================
// Allows sequencing goals with parallel execution within each GoalGroup

const int MAX_QUEUE_STEPS = 99;

struct QueuedGoal {
  int motorIndex;       // Which motor (0-5), or -1 if slot empty
  JointGoal goal;       // What goal (FIND_HOME, MOVE_TO, etc.)
  long targetPosition;  // For MOVE_TO goals
};

struct QueueGoalGroup {
  QueuedGoal goals[6];           // Up to 6 parallel goals per GoalGroup
  int goalCount;                 // How many goals in this GoalGroup
  const char* name;              // Motor name for debugging
  unsigned long waitDurationMs;  // If >0, this is a wait step (no motor goals)
  unsigned long waitStartTime;   // When wait started (set at dispatch time)
};

// Queue state
QueueGoalGroup goalQueue[MAX_QUEUE_STEPS];
int currentQueueGoalGroup = -1;  // -1 = queue not running, >= 0 = executing that GoalGroup
int totalQueueGoalGroups = 0;    // Total steps defined in queue
int buildingGoalGroup = -1;      // Which GoalGroup we're currently adding goals to
bool queueFaulted = false;       // True if queue stopped due to motor fault

// ============================================================================
// STATE INITIALIZATION
// ============================================================================

inline void initializeAllJointStates() {
  for (int i = 0; i < ScorbotJointIndex_COUNT; i++) {
    jointState[i].hasFoundHome = false;

    jointState[i].motorSpeed = 0;

    jointState[i].currentGoal = GOAL_IDLE;
    jointState[i].goalStartTime = 0;

    jointState[i].targetEncoderCountToMoveTo = 0;
    jointState[i].maxEncoderStepsFromHomeCW = 0;   // 0 = uncalibrated
    jointState[i].maxEncoderStepsFromHomeCCW = 0;  // 0 = uncalibrated
    jointState[i].lastHomeSwitchDebounceTime = 0;

    jointState[i].encoderCount = 0;
    jointState[i].lastEncoderCount = 0;
    jointState[i].lastEncoded = 0;

    jointState[i].lastEncoderCheckTime = millis();  // Initialize encoder check time
    jointState[i].stallCounter = 0;
    jointState[i].totalStallsThisGoal = 0;
  }
}

// ============================================================================
// MOTOR CONTROL FUNCTIONS
// ============================================================================

// ------------------------------------------------------------------------

inline void setMotor(int ScorbotJointIndex, int speed, bool isDifferentialActive = true) {
  if (ScorbotJointIndex < 0 || ScorbotJointIndex >= ScorbotJointIndex_COUNT)
    return;
  if (speed < -99 || speed > 99)
    return;

  // Store the abstract/logical speed in jointState
  jointState[ScorbotJointIndex].motorSpeed = speed;

  // Serial.print("setMotor ");
  // Serial.print(SCORBOT_REF[ScorbotJointIndex].name);
  // Serial.print(", ");
  // Serial.println(speed);

  // DIFFERENTIAL DRIVE FOR WRIST
  // For wrist pitch/roll, differential control is needed because the physical
  // motors are coupled - moving one motor alone produces combined pitch+roll
  // motion. The differential math produces pure pitch or pure roll motion.
  if (isDifferentialActive && (ScorbotJointIndex == MOTOR_WRIST_PITCH || ScorbotJointIndex == MOTOR_WRIST_ROLL)) {
    // Apply differential motor commands to both physical motors
    // Reads abstract speeds from jointState and calculates physical motor outputs
    int motor4Speed, motor5Speed;

    // Differential math based on mechanical coupling
    // motors Same direction = pitch, Opposite direction = roll
    // old code for reference and debugging
    // // makes wrist pitch up only
    // digitalWrite(SCORBOT_REF[MOTOR_WRIST_PITCH].CW_pin, HIGH);
    // digitalWrite(SCORBOT_REF[MOTOR_WRIST_PITCH].CCW_pin, LOW);
    // digitalWrite(SCORBOT_REF[MOTOR_WRIST_ROLL].CW_pin, HIGH);
    // digitalWrite(SCORBOT_REF[MOTOR_WRIST_ROLL].CCW_pin, LOW);

    // //  wrist pitch down,
    // digitalWrite(SCORBOT_REF[MOTOR_WRIST_PITCH].CW_pin, LOW);
    // digitalWrite(SCORBOT_REF[MOTOR_WRIST_PITCH].CCW_pin, HIGH);
    // digitalWrite(SCORBOT_REF[MOTOR_WRIST_ROLL].CW_pin, LOW);
    // digitalWrite(SCORBOT_REF[MOTOR_WRIST_ROLL].CCW_pin, HIGH);

    // wrist pitch nothing , clockwise roll
    // digitalWrite(SCORBOT_REF[MOTOR_WRIST_PITCH].CW_pin, LOW);
    // digitalWrite(SCORBOT_REF[MOTOR_WRIST_PITCH].CCW_pin, HIGH);
    // digitalWrite(SCORBOT_REF[MOTOR_WRIST_ROLL].CW_pin, HIGH);
    // digitalWrite(SCORBOT_REF[MOTOR_WRIST_ROLL].CCW_pin, LOW);

    // wrist pitch nothing  counter clockwise roll
    // digitalWrite(SCORBOT_REF[MOTOR_WRIST_PITCH].CW_pin, HIGH);
    // digitalWrite(SCORBOT_REF[MOTOR_WRIST_PITCH].CCW_pin, LOW);
    // digitalWrite(SCORBOT_REF[MOTOR_WRIST_ROLL].CW_pin, LOW);
    // digitalWrite(SCORBOT_REF[MOTOR_WRIST_ROLL].CCW_pin, HIGH);

    int raw_motor4 = jointState[MOTOR_WRIST_PITCH].motorSpeed -
                     jointState[MOTOR_WRIST_ROLL].motorSpeed;  // Pitch motor (physical motor 4)
    int raw_motor5 = jointState[MOTOR_WRIST_PITCH].motorSpeed +
                     jointState[MOTOR_WRIST_ROLL].motorSpeed;  // Roll motor (physical motor 5)

    // Proportional scaling to maintain motion ratio
    int maxAbsValue = max(abs(raw_motor4), abs(raw_motor5));
    if (maxAbsValue > 99) {
      float scaleFactor = 99.0 / maxAbsValue;
      raw_motor4 = (int)(raw_motor4 * scaleFactor);
      raw_motor5 = (int)(raw_motor5 * scaleFactor);
    }

    // Clamp to valid range (safety)
    motor4Speed = constrain(raw_motor4, -99, 99);
    motor5Speed = constrain(raw_motor5, -99, 99);

    // Apply to physical motors using direct control (bypasses differential logic)
    setMotorDirect(MOTOR_WRIST_PITCH, motor4Speed);
    setMotorDirect(MOTOR_WRIST_ROLL, motor5Speed);

    return;
  }

  // NORMAL (NON-DIFFERENTIAL) MOTOR CONTROL
  setMotorDirect(ScorbotJointIndex, speed);
}

// ------------------------------------------------------------------------
// Direct motor control - sets physical motor without differential interception
// Used internally by differential system to avoid recursion
inline void setMotorDirect(int ScorbotJointIndex, int speed) {
  if (ScorbotJointIndex < 0 || ScorbotJointIndex >= ScorbotJointIndex_COUNT)
    return;
  if (speed < -99 || speed > 99)
    return;

  // Debug output for wrist motors
  // if (ScorbotJointIndex == MOTOR_WRIST_PITCH || ScorbotJointIndex == MOTOR_WRIST_ROLL) {
  //   Serial.print("setMotor Direct ");
  //   Serial.print(SCORBOT_REF[ScorbotJointIndex].name);
  //   Serial.print(", ");
  //   Serial.print(speed);
  //   Serial.println();
  // }

  int motor_min = 0;
  int pwmValue = 0;

  if (speed > 0) {  // clockwise
    motor_min = SCORBOT_REF[ScorbotJointIndex].motor_min_CW;
    digitalWrite(SCORBOT_REF[ScorbotJointIndex].CW_pin, HIGH);
    digitalWrite(SCORBOT_REF[ScorbotJointIndex].CCW_pin, LOW);
  } else if (speed < 0) {  // counter clockwise
    motor_min = SCORBOT_REF[ScorbotJointIndex].motor_min_CCW;
    digitalWrite(SCORBOT_REF[ScorbotJointIndex].CW_pin, LOW);
    digitalWrite(SCORBOT_REF[ScorbotJointIndex].CCW_pin, HIGH);
  } else {  // stop
    digitalWrite(SCORBOT_REF[ScorbotJointIndex].CCW_pin, LOW);
    digitalWrite(SCORBOT_REF[ScorbotJointIndex].CW_pin, LOW);
    analogWrite(SCORBOT_REF[ScorbotJointIndex].pwm_pin, 0);
    // Don't modify jointState.motorSpeed here - that's the logical speed managed by setMotor()
    return;
  }

  // Don't modify jointState.motorSpeed here - that's the logical speed managed by setMotor()
  pwmValue = map(abs(speed), 0, 99, motor_min, 255);
  analogWrite(SCORBOT_REF[ScorbotJointIndex].pwm_pin, pwmValue);
}

// ------------------------------------------------------------------------
// Stop a motor
// Usage: stopMotor(MOTOR_BASE);
inline void stopMotor(int ScorbotJointIndex, bool isDifferentialActive = true) {
  // Serial.print(SCORBOT_REF[ScorbotJointIndex].name);
  // Serial.println(" stopMotor");

  setMotor(ScorbotJointIndex, 0, isDifferentialActive);
}

// ============================================================================
// GOAL QUEUE FUNCTIONS
// ============================================================================

// Clear and reset the queue
inline void queueClear() {
  currentQueueGoalGroup = -1;
  totalQueueGoalGroups = 0;
  buildingGoalGroup = -1;
  queueFaulted = false;

  // Zero out all queue data
  for (int s = 0; s < MAX_QUEUE_STEPS; s++) {
    goalQueue[s].goalCount = 0;
    for (int g = 0; g < 6; g++) {
      goalQueue[s].goals[g].motorIndex = -1;
      goalQueue[s].goals[g].goal = GOAL_IDLE;
      goalQueue[s].goals[g].targetPosition = 0;
    }
  }

  // Serial.println("Queue: Cleared");
}

// Begin defining a new group (call before adding goals to that GoalGroup)
inline void queueCreateGoalGroup(const char* groupName = "") {
  if (totalQueueGoalGroups >= MAX_QUEUE_STEPS) {
    Serial.println("Queue: ERROR - max steps reached!");
    return;
  }

  buildingGoalGroup = totalQueueGoalGroups;
  totalQueueGoalGroups++;
  goalQueue[buildingGoalGroup].goalCount = 0;
  goalQueue[buildingGoalGroup].name = groupName;
  goalQueue[buildingGoalGroup].waitDurationMs = 0;
  goalQueue[buildingGoalGroup].waitStartTime = 0;

  // Serial.print("Queue: Creating GoalGroup ");
  // Serial.print(buildingGoalGroup);
  // if (groupName[0] != '\0') {
  //   Serial.print(" (");
  //   Serial.print(groupName);
  //   Serial.print(")");
  // }
  // Serial.println();
}

// Add a goal to the current GoalGroup being built
inline void queueAddGoal(int motorIndex, JointGoal goal, long targetPosition = 0) {
  if (buildingGoalGroup < 0 || buildingGoalGroup >= MAX_QUEUE_STEPS) {
    Serial.println("Queue: ERROR - call queueCreateGoalGroup() first!");
    return;
  }

  int count = goalQueue[buildingGoalGroup].goalCount;
  if (count >= 6) {
    Serial.println("Queue: ERROR - max 6 goals per GoalGroup!");
    return;
  }

  goalQueue[buildingGoalGroup].goals[count].motorIndex = motorIndex;
  goalQueue[buildingGoalGroup].goals[count].goal = goal;
  goalQueue[buildingGoalGroup].goals[count].targetPosition = targetPosition;
  goalQueue[buildingGoalGroup].goalCount++;

  // Serial.print("Queue:   Added ");
  // Serial.print(SCORBOT_REF[motorIndex].name);
  // Serial.print(" -> ");
  // Serial.println(MOTOR_GOAL_NAMES[goal]);
}

// Add a wait step - creates its own GoalGroup that waits for the specified duration
inline void queueCreateGoalGroupWait(unsigned long durationMs, const char* name = "wait") {
  if (totalQueueGoalGroups >= MAX_QUEUE_STEPS) {
    Serial.println("Queue: ERROR - queue full!");
    return;
  }

  int stepIdx = totalQueueGoalGroups;
  goalQueue[stepIdx].goalCount = 0;
  goalQueue[stepIdx].name = name;
  goalQueue[stepIdx].waitDurationMs = durationMs;
  goalQueue[stepIdx].waitStartTime = 0;
  totalQueueGoalGroups++;
  buildingGoalGroup = -1;  // Not building a motor goal group

  // Serial.print("Queue: Added wait step ");
  // Serial.print(stepIdx);
  // Serial.print(" (");
  // Serial.print(durationMs);
  // Serial.println(" ms)");
}

// Dispatch all goals for a given GoalGroup
inline void queueDispatchStep(int stepIndex) {
  if (stepIndex < 0 || stepIndex >= totalQueueGoalGroups)
    return;

  QueueGoalGroup* GoalGroup = &goalQueue[stepIndex];

  // Handle wait steps
  if (GoalGroup->waitDurationMs > 0) {
    GoalGroup->waitStartTime = millis();
    Serial.print("Queue: Starting wait step ");
    Serial.print(stepIndex);
    Serial.print(" (");
    Serial.print(GoalGroup->waitDurationMs);
    Serial.println(" ms)");
    return;
  }

  Serial.print("Queue: Starting GoalGroup ");
  Serial.print(stepIndex);
  if (GoalGroup->name != nullptr && GoalGroup->name[0] != '\0') {
    Serial.print(" (");
    Serial.print(GoalGroup->name);
    Serial.print(")");
  }
  Serial.print(" with ");
  Serial.print(GoalGroup->goalCount);
  Serial.println(" goal(s)");

  for (int g = 0; g < GoalGroup->goalCount; g++) {
    QueuedGoal* qg = &GoalGroup->goals[g];
    if (qg->motorIndex >= 0 && qg->motorIndex < ScorbotJointIndex_COUNT) {
      // For MOVE_TO and MOVE_TILL_STALL goals, set the target/speed first
      if (qg->goal == GOAL_MOVE_TO || qg->goal == GOAL_MOVE_TILL_STALL) {
        jointState[qg->motorIndex].targetEncoderCountToMoveTo = qg->targetPosition;
      }
      startGoal(qg->motorIndex, qg->goal);
    }
  }
}

// Start executing the queue from GoalGroup 0
inline void queueStart() {
  if (totalQueueGoalGroups == 0) {
    Serial.println("Queue: ERROR - no steps defined!");
    return;
  }

  queueFaulted = false;
  currentQueueGoalGroup = 0;

  // Serial.print("Queue: Starting execution with ");
  // Serial.print(totalQueueGoalGroups);
  // Serial.println(" GoalGroup(s)");

  queueDispatchStep(0);
}

// Check if queue is currently running
inline bool queueIsRunning() {
  return currentQueueGoalGroup >= 0 && !queueFaulted;
}

// Check if queue stopped due to fault
inline bool queueIsFaulted() {
  return queueFaulted;
}

// Check if current GoalGroup is complete and advance to next GoalGroup if so
// Call this in the main loop
inline void queueAdvanceIfReady() {
  if (currentQueueGoalGroup < 0 || queueFaulted)
    return;  // Queue not running

  QueueGoalGroup* GoalGroup = &goalQueue[currentQueueGoalGroup];
  bool allComplete = true;

  // Handle wait steps
  if (GoalGroup->waitDurationMs > 0) {
    if (millis() - GoalGroup->waitStartTime < GoalGroup->waitDurationMs) {
      return;  // Still waiting
    }
    // Wait complete, fall through to advance
    // Serial.print("Queue: Wait step ");
    // Serial.print(currentQueueGoalGroup);
    // Serial.println(" complete");
  } else {
    // Check all goals in current GoalGroup
    for (int g = 0; g < GoalGroup->goalCount; g++) {
      int motorIdx = GoalGroup->goals[g].motorIndex;
      if (motorIdx < 0 || motorIdx >= ScorbotJointIndex_COUNT)
        continue;

      JointGoal state = jointState[motorIdx].currentGoal;

      // Check for fault
      if (state == GOAL_FAULT) {
        Serial.print("Queue: FAULT on ");
        Serial.print(SCORBOT_REF[motorIdx].name);
        Serial.print(" at GoalGroup ");
        Serial.print(currentQueueGoalGroup);
        Serial.print(" ");
        Serial.print(goalQueue[currentQueueGoalGroup].name);
        Serial.println(" - queue stopped and cleared");
        queueFaulted = true;
        return;
      }

      // Check if still running (not IDLE)
      if (state != GOAL_IDLE) {
        allComplete = false;
      }
    }

    if (!allComplete)
      return;  // Still waiting for goals to finish
  }

  // All goals in current GoalGroup complete!
  // Serial.print("Queue: GoalGroup ");
  // Serial.print(currentQueueGoalGroup);
  // Serial.println(" complete");

  // Advance to next GoalGroup
  currentQueueGoalGroup++;

  if (currentQueueGoalGroup >= totalQueueGoalGroups) {
    // Queue finished!
    Serial.println("Queue: All steps complete");
    currentQueueGoalGroup = -1;  // Mark queue as not running
    return;
  }

  // Dispatch next GoalGroup
  queueDispatchStep(currentQueueGoalGroup);
}
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
void loop() {
  // Emergency stop check - first thing in loop
  if (digitalRead(ESTOP_PIN) == LOW) {
    for (int i = 0; i < ScorbotJointIndex_COUNT; i++) {
      stopMotor(i);
      jointState[i].currentGoal = GOAL_FAULT;
    }
    // Also halt the queue on E-stop
    if (queueIsRunning()) {
      queueFaulted = true;
      Serial.println("Queue: Halted by E-STOP");
    }
    Serial.println("EMERGENCY STOP");
    while (digitalRead(ESTOP_PIN) == LOW) {
      delay(10);  // Wait for button release
    }
    Serial.println("E-Stop released - reset to continue");
    return;  // Skip rest of loop until reset
  }

  updateAllEncoders();  // CRITICAL: Update all encoders every loop

  checkAllStalls();

  checkAllHomeSwitches();

  // Update all active goals
  doAllGoals();

  // Check if queue GoalGroup is complete and advance
  queueAdvanceIfReady();

  delay(1);
}

// ============================================================================
// SETUP
// ============================================================================

void setup() {
  Serial.begin(115200);
  delay(500);  // Brief delay to allow Serial to initialize
  // Clear any old data in the buffer
  while (Serial.available() > 0) {
    Serial.read();
  }

  Serial.println("\n\n=============SCORBOT START==============");

  // Initialize hardware
  setupAllPins();
  initializeAllJointStates();

  // Safety: stop all motors
  for (int i = 0; i < ScorbotJointIndex_COUNT; i++) {
    stopMotor(i);
  }

  // Build sequence using the goal queue
  // GoalGroups execute sequentially, goals within each group run in parallel
  queueClear();

  queueAddGoalsFindHomeAll();

  queueCreateGoalGroupWait(1000);  // Wait 1 second, pauses all goals

  queueCreateGoalGroup("move base");
  queueAddGoal(MOTOR_BASE, GOAL_MOVE_TO, 1050);  // Move to encoder position

  queueCreateGoalGroup("open gripper");
  queueAddGoal(MOTOR_GRIPPER, GOAL_MOVE_TO, -400);  // all gripper positions are negative, 0 is closed
  queueAddGoal(MOTOR_WRIST_ROLL, GOAL_MOVE_TO, -100);
  queueAddGoal(MOTOR_SHOULDER, GOAL_MOVE_TO, -1000);  // negative is move down

  queueCreateGoalGroupWait(1000);  // Wait 1 second, pauses all goals

  queueCreateGoalGroup("Grab item");
  queueAddGoal(MOTOR_GRIPPER, GOAL_MOVE_TILL_STALL, 50);  // Close at 50% speed until stall
  // queueAddGoal(MOTOR_WRIST_ROLL, GOAL_MOVE_TO, 50);

  queueCreateGoalGroup("Flip item");
  queueAddGoal(MOTOR_WRIST_PITCH, GOAL_MOVE_TO, 700);

  queueCreateGoalGroup("go to new position");
  queueAddGoal(MOTOR_SHOULDER, GOAL_MOVE_TO, 1000);  // positive is move up
  queueAddGoal(MOTOR_BASE, GOAL_MOVE_TO, 1000);      // Move to encoder position

  queueCreateGoalGroupWait(1000);  // Wait 1 second, pauses all goals

  queueCreateGoalGroup("spin item");

  // queueAddGoal(MOTOR_WRIST_ROLL, GOAL_RETURN_HOME);
  queueAddGoal(MOTOR_WRIST_ROLL, GOAL_MOVE_TO, 200);

  queueCreateGoalGroup("base return home");
  queueAddGoal(MOTOR_BASE, GOAL_RETURN_HOME);

  queueStart();  // Begin executing the queue
}

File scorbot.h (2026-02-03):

/*
SCORBOT ER III - PIN DEFINITIONS

This file defines all Arduino Mega pin assignments for the Scorbot robot.
Include this file in any sketch to ensure consistent pin usage.

Based on DB-50 connector wiring and L298N motor driver configuration.


  Access motor pins through the `SCORBOT_REF[]` array:

  ```arduino
  // Move base motor clockwise at 50% speed
  digitalWrite(SCORBOT_REF[MOTOR_BASE].dir1, HIGH);
  digitalWrite(SCORBOT_REF[MOTOR_BASE].dir2, LOW);
  analogWrite(SCORBOT_REF[MOTOR_BASE].pwm, 128);

  // Check shoulder home switch
  bool atHome = (digitalRead(SCORBOT_REF[MOTOR_SHOULDER].home_switch) == LOW);

  // Read elbow encoder
  int p0 = digitalRead(SCORBOT_REF[MOTOR_ELBOW].encoder_p0);
  int p1 = digitalRead(SCORBOT_REF[MOTOR_ELBOW].encoder_p1);

  // Print motor name for debugging
  Serial.println(SCORBOT_REF[MOTOR_BASE].name);  // Prints "Base"


Home is 0
CW is positive steps
CCW is negative steps
for example Base CCW to home: -7338 CW to home:5734

CW closes gripper "Righty-tighty"
CW for wrist roll is normal human wrist direction


*/

#ifndef SCORBOT_PINS_H
#define SCORBOT_PINS_H

#include <string.h>  // For strcmp() function

// ============================================================================
// SERIAL COMMUNICATION
// ============================================================================
// Note: Serial1 uses pins 18 (TX) and 19 (RX) on Arduino Mega
// These are used for communication with external joystick controller
#define SERIAL_TX 18  // Reserved for Serial1
#define SERIAL_RX 19  // Reserved for Serial1

// ============================================================================
// EMERGENCY STOP - Connect momentary button between pin 52 and GND
// ============================================================================
#define ESTOP_PIN 52

struct Scorbot_joints_reference {
  int CCW_pin;          // Direction pin (H-bridge IN1 or IN3)
  int CW_pin;           // Direction pin (H-bridge IN2 or IN4)
  int pwm_pin;          // PWM speed control pin (H-bridge ENA or ENB)
  int encoder_p0_pin;   // Encoder channel P0
  int encoder_p1_pin;   // Encoder channel P1
  int home_switch_pin;  // Home microswitch pin
  const char* name;     // Motor name for debugging
  int motor_min_CCW;    // minimum to make motor move
  int motor_min_CW;     // minimum to make motor move
};

// Motor axis indices (for array access)
enum ScorbotJointIndex {
  MOTOR_BASE = 0,
  MOTOR_SHOULDER,
  MOTOR_ELBOW,
  MOTOR_WRIST_PITCH,
  MOTOR_WRIST_ROLL,
  MOTOR_GRIPPER,
  ScorbotJointIndex_COUNT  // this is the count of the enum, gets a value assigned automagically
};

// Main Scorbot motor configuration array
// Usage: SCORBOT_REF[MOTOR_BASE].pwm_pin or SCORBOT_REF[0].pwm_pin
// Using array designators to prevent enum/array order mismatch
const Scorbot_joints_reference SCORBOT_REF[ScorbotJointIndex_COUNT] = {

    // ============================================================================
    //  BASE (310° rotation)
    // L298N Board 1, Motor A (Output 1)
    [MOTOR_BASE] =
        {
            .CCW_pin = 22,
            .CW_pin = 23,
            .pwm_pin = 7,
            .encoder_p0_pin = 34,
            .encoder_p1_pin = 35,
            .home_switch_pin = 46,
            .name = "base",
            .motor_min_CCW = 40,  // 0-255
            .motor_min_CW = 45    // 0-255
        },

    // ============================================================================
    // SHOULDER (+130° / -35°)
    // ============================================================================
    // L298N Board 1, Motor B (Output 2)

    [MOTOR_SHOULDER] =
        {
            .CCW_pin = 24,
            .CW_pin = 25,
            .pwm_pin = 6,
            .encoder_p0_pin = 36,
            .encoder_p1_pin = 37,
            .home_switch_pin = 47,
            .name = "shoulder",
            .motor_min_CCW = 200,  // 0-255
            .motor_min_CW = 200    // 0-255
        },

    // ============================================================================
    // ELBOW (±130°)
    // ============================================================================
    // L298N Board 2, Motor A (Output 1)

    [MOTOR_ELBOW] =
        {
            .CCW_pin = 27,
            .CW_pin = 26,
            .pwm_pin = 5,
            .encoder_p0_pin = 38,
            .encoder_p1_pin = 39,
            .home_switch_pin = 48,
            .name = "elbow",
            .motor_min_CCW = 255,  // 0-255
            .motor_min_CW = 255    // 0-255
        },

    // ============================================================================
    // WRIST PITCH (±130°)
    // ============================================================================
    // L298N Board 2, Motor B (Output 2)
    [MOTOR_WRIST_PITCH] =
        {
            .CCW_pin = 29,  // Swapped to fix direction
            .CW_pin = 28,
            .pwm_pin = 4,
            .encoder_p0_pin = 41,
            .encoder_p1_pin = 40,
            .home_switch_pin = 49,
            .name = "wrist_pitch",
            .motor_min_CCW = 200,  // 0-255
            .motor_min_CW = 200    // 0-255
        },

    // ============================================================================
    // WRIST ROLL (unlimited rotation)
    // ============================================================================
    // L298N Board 3, Motor A (Output 1)
    [MOTOR_WRIST_ROLL] =
        {
            .CCW_pin = 30,
            .CW_pin = 31,
            .pwm_pin = 3,
            .encoder_p0_pin = 42,
            .encoder_p1_pin = 43,
            .home_switch_pin = 50,
            .name = "wrist_roll",
            .motor_min_CCW = 200,  // 0-255
            .motor_min_CW = 200    // 0-255
        },

    // ============================================================================
    // GRIPPER
    // ============================================================================
    // L298N Board 3, Motor B (Output 2)
    // Clockwise closes gripper
    [MOTOR_GRIPPER] = {
        .CCW_pin = 33,
        .CW_pin = 32,
        .pwm_pin = 2,
        .encoder_p0_pin = 45,  // Swapped with p1 to invert encoder direction
        .encoder_p1_pin = 44,
        .home_switch_pin = 51,
        .name = "gripper",
        .motor_min_CCW = 200,  // 0-255
        .motor_min_CW = 200    // 0-255
    }};

// ============================================================================
// MOTOR CONTROL FUNCTIONS
// ============================================================================
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

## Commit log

2025-12-16 updated wiring list
2026-01-03 updated arduino pins to be uniform rows. committing table 2 and 3 as references befoe I delete them
    [scorbot joint cover with microswitch cam.stl]
2026-01-08 basic wiring done and pin tests ok
2026-01-08 improved header code, all motors are moving back and forth in helpers/motor_only_test/motor_only_test.ino
2026-01-09 base motor is improved, moved on to helpers/multi_motor_homing/multi_motor_homing.ino with more code in scorbot.h am able to reliably do homing with base motor
2026-01-13 base and shoulder work, but elbow stalls without reversing. plan to build new code from scratch to simplify conceptually
    [scorbot.h]
2026-01-14 foundation is coming along. GOAL_FIND_HOME works for base and shoulder. elbow has a hardware issue: CW stall gets stuck
    [foundation.ino, scorbot.h]
2026-01-14 gripper home with stall of closed gripper. Still elbow and wrist pitch are getting stall stuck despite extra code. next will explore moving pitch and elbow
    [foundation.ino, scorbot.h]
2026-01-16 MOTOR_ELBOW was a big pain, would not go CCW. turned out the CCW pin (arduinio pin 27) was loose
    [foundation.ino]
2026-01-17 writst roll and pitch now work, using differential drives for both motors
2026-01-17 fix typo, inlined calculateDifferentialMotorSpeeds to avoid pointers!
    [foundation.ino]
2026-01-17 added Emergency stop to pin 52
2026-01-17 added e stop pin to diagram
2026-01-18 homing queue is working, next working on GOAL_MOVE_TO which is only partly working, some stall bug
    [foundation.ino, scorbot.h]
2026-01-18 changes serial rate to 115200 baud, which fixes the weird start/restart when programming bug
    [foundation.ino]
2026-01-18 commented out #include <Arduino.h> makes VScode outline view work. Arduino IDE auto includes it
2026-01-18 reset totalStallsThisGoal in attempt to eliminate false stalls
    [foundation.ino]
2026-01-18 broght back #include <Arduino.h> to avoid fasle errors. added "files.associations": { "*.ino": "cpp" } for better linting
    [foundation.ino]
2026-01-18 enhanced edge detection on home switch to remove false home triggering
2026-01-18 complete run with all home tests and joint move to's! Elbow joint is still the stickiest
2026-01-18 moved setup and loop to end of file for convenience. • moved setmotor to front to remove forward declarations
2026-01-18 added better home detection if starting on home switch, makes much faster
2026-02-03 •added GOAL_MOVE_TILL_STALL for gripper grab • made demo program more complex, to pick up toy • updated images • swapped wrist encoder pins as were counting in the wrong direction
    [scorbotIIIER-controller-base.stl, scorbotIIIER-controller-top.stl]
2026-02-04 updated readme with current state
